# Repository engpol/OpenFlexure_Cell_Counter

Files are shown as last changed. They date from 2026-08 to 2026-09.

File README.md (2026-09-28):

# OpenFlexure Cell Counter

A simple automated cell counter built on the [OpenFlexure Microscope](https://openflexure.org/),
using either traditional contrast-based or deep-learning segmentation to count cells in suspension to assist in calculating
concentrations — all in under 60 seconds, without a haemocytometer!

### Cell Counter

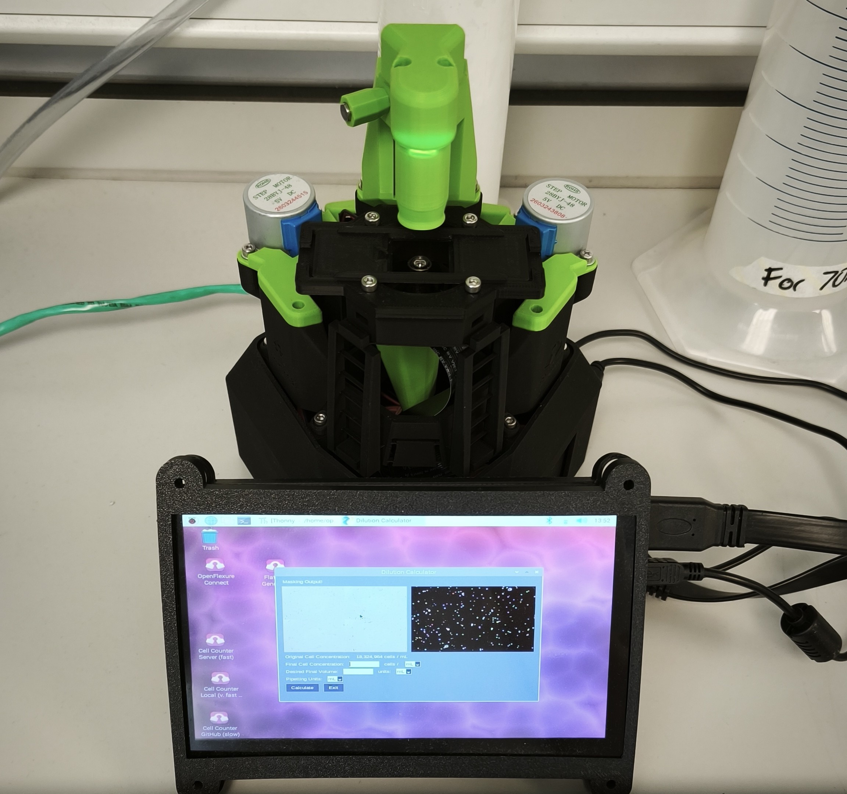
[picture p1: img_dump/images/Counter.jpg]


### GUI

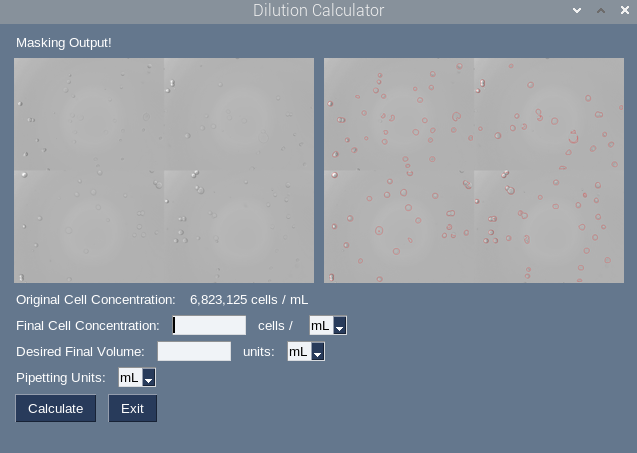
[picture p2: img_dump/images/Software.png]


---

## Contents

- [What this is](#what-this-is)
- [Who it's for](#who-its-for)
- [How it works](#how-it-works)
- [What you'll need](#what-youll-need)
- [Getting started](#getting-started)
- [Daily use](#daily-use)
- [Validating your instrument](#validating-your-instrument)
- [Limitations](#limitations)
- [Troubleshooting](#troubleshooting)
- [Contributing](#contributing)
- [Licence and citation](#licence-and-citation)

---

## What this is

Counting cells with a haemocytometer is slow, tedious, and notoriously variable
between operators. Automated cell counters solve this but cost several thousand
pounds, lock you into proprietary consumables, and are impossible to repair yourself.

This project turns an [OpenFlexure Microscope](https://www.youtube.com/watch?v=InmLDDsRmb4) — an open-source, 3D-printed,
motorised microscope — into an automated cell counter. You pipette your suspension onto a coverslip, press a button, and get a cell count and
concentration back in a few seconds. To see the cell counter in action [click here!](#daily-use)

>As a side-note, the microscope is a fully motorized and customisable brightfield microscope; the software provided here is simply a single use-case. If you ever invest in a professional cell counter, this can easily be re-purposed for another project!

There are 2 options for performing cell segmentation; either a traditional threshold-and-watershed approach or one that uses [Cellpose](https://www.cellpose.org/), a deep-learning model that handles
touching, overlapping, and irregularly shaped cells far better.

The Cellpose model included in this repo is **cyto2** fine tuned on images of HEK-293 cells taken on several different OpenFlexure microscopes. It is very easy to use it, or even one you have trained yourself, and it is covered in the server setup guide.

### Accuracy of Cell Counter

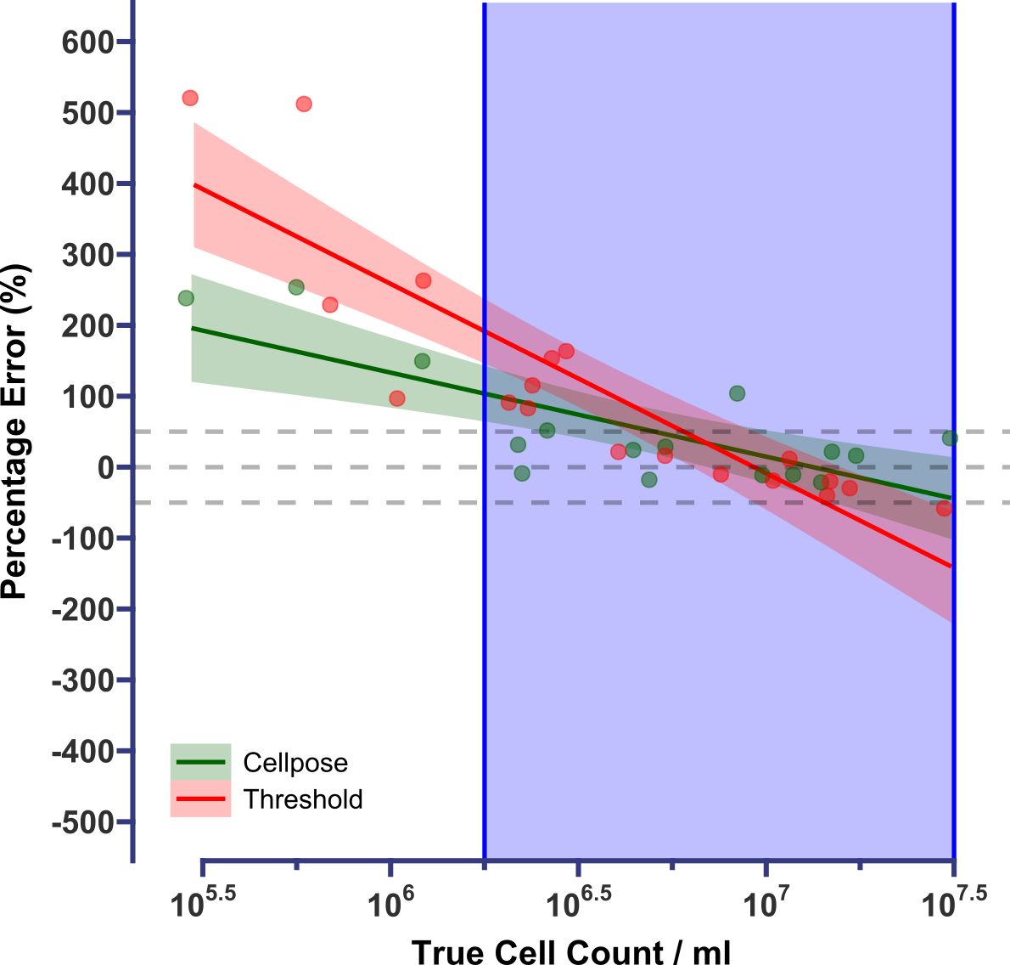
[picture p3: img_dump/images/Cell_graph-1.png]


**Shown above is a comparison of the cell counts given by my cell counter to those calculated by an Invitrogen Cell Countess to get an estimate of the expected error at different suspension concentrations.**

Across most of the range of initial concentrations of cell suspensions from semi-confluent to confluent T25-T175 flasks (*blue box*), both methods performed similarily and varied by less than 50% (*grey dotted line*) from the Cell Countess. 

### In this range, a **mean error** of **19.1%** (*Cellpose*) and **34.2%** (*Threshold*) were achieved. 
This is within the range of [expected error in manual cell counting](https://chemometec.com/how-to-count-cells-with-a-hemocytometer/) (20-30%) which makes both methods suitable substitutions to the use of a haemocytometer for a lot of cell culture experiments.

---

## Who it's for

>This Cell Counter is for people working in cell culture who routinely need to perform cell suspension dilution calculations, who may not need/want to spend thousands on more advanced systems. 

This counter, as the OpenFlexure Microscope itself, is designed to be assembled and be usable by someone with **no programming or engineering experience**. The setup involves a few one-time steps for which detailed click-by-click guides have been written out; after that, daily use is a graphical interface with a few buttons.

You will need to be comfortable with:

- Pipetting onto a coverslip
- Following a step-by-step setup guide once

You will **not** need to write your own code, use a command line day-to-day, or
understand how the machine learning works. However, information on all of the code is provided if you would wish to adapt/improve on what I have made here. 

---

## How it works

The process of counting cells is functionally identical to what can be done manually in a haemocytometer. However we can use the fact that the exact effective field of view of the camera is known, to forgo the need for a machined chamber.  

The microscope photographs **four fields of view**, which together cover a small
fraction of the coverslip:

| Quantity | Value |
|---|---|
| Area of one field of view | 0.0584 mm² |
| Four fields combined | 0.2336 mm² |
| Area of a 22 × 22 mm coverslip | 484 mm² |
| **Fraction of the sample you actually see** | **1 / 2072** |

Then the microscope will use one of either methods to calculate the number of cells across all 4 images.

So if the microscope counts 150 cells:

```
Total cells on coverslip  = 150 × 2072  = 310,800 cells
Volume pipetted           = 50 µL       = 0.05 mL
Concentration             = 310,800 / 0.05 = 6.2 × 10⁶ cells/mL
```

This calculation only works on assumption the cells are **evenly distributed** across the coverslip. Thus it is important to let the
sample settle, mix it thoroughly before pipetting, and take a second reading if a
number looks surprising.

---

## What you'll need

### Hardware

| Item | Notes | Approx. cost |
|---|---|---|
| [OpenFlexure Microscope](https://openflexure.org/) | Simple optics are sufficient and use most up-to-date hardware version | ~100£ or ~160£ from a vendor (Exluding RPi) |
| Raspberry Pi 4B | I used 4GB model, but 2 GB should be sufficient | These have recently got more expensive, so including separate to microscope. Expect 50-90£ |
| Microscope Peripherals | You'll need a seperate screen/mouse + keyboard to control the microscope. The cost will depend on how compact you want it to be. I used a [very small screen](https://www.amazon.co.uk/ELECROW-Touchscreen-1024x600-Compatible-Raspberry/dp/B0G5YL9Z66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) I found on amazon and an old bluetooth mouse/keyboard I found in the office. | Existing hardware or ~50£ |
| Analysis computer (Optional) | Any old PC that can be connected to the scope via an ethernet cable. Helps tremendously if it has any NVIDIA Graphics card supporting CUDA, but is not an absolute requirement. | Existing hardware |
| Ethernet cable (Optional) | Ordinary cable | ~£5 |
| 22 × 22 mm glass coverslips | Whatever's cheapest, I just wash and re-use mine until they crack | £5 |
| Additional 3D-printed parts | The 2 STLs in [`STLs/Custom_Holder`](STLs/Custom_Holder/) | Filament cost or ~10£ if using external service |

### Total Cost:

**~ 200£** (Excluding optional Analysis PC/peripherals - the cost of this will vary depending on what you have lying around) 

### Software

Everything needed is free and open-source. The easiest way to get the cell counter running is by using the pre-configured image which can be downloaded using the button below (~9.1 GB). In time, I may try to get this working as a PyPi package.



---

## Getting started

Budget about **two hours** for first-time setup, excluding building the microscope.

### 1. Build the microscope

Acquire all parts required for the "Basic Optics" variant of the Open Flexure Microscope, and follow the [OpenFlexure assembly instructions](https://build.openflexure.org/) to build the microscope. Please check out the list of [associated vendors](https://openflexure.org/about/vendors) if you would prefer to simply buy a complete assembly kit for the microscope. I have included all STL files needed for the [OpenFlexure v7](STLs/OpenFlexure_v7_Beta) in this repo for your benefit. 

Then, once you have finished the build, just screw on the [`counting chamber`](STLs/Custom_Holder/counting_chamber.stl) from [`STLs`](STLs/Custom_Holder) onto the sample stage using 4 M3 bolts (the same type that you used to hold the sample clips in place). 

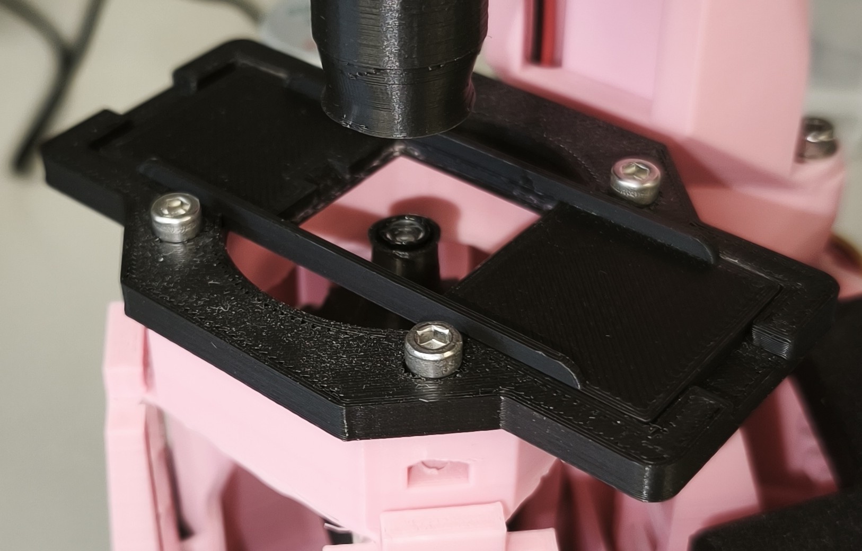
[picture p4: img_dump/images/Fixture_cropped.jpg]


### 2. Flash the Raspberry Pi

Download the pre-configured image (link above) and write it to an SD card with
[Raspberry Pi Imager](https://www.raspberrypi.com/software/). Put the SD card into your OF microscope, and boot it up. Everything —
base OpenFlexure microscope software, network settings, Cell Counter software — is already installed. 

I recommend a 32 GB SSD, but anything above 10 GB should be fine.
The thresholding-watershed method for Cell Segmentation can run directly from the RPi so, if you do not wish to run Cellpose, this is all you would need to have a functional Cell Counter!

### 3. OPTIONAL - IF USING CELLPOSE - Set up Server

If wanting to use Cellpose for segmentation, you will need a second computer to run the Cellpose segmentation. 

Sadly, some of the Cellpose dependencies (Torch) are very hard to setup and run dreadfully slow on the 32-bit ARM OS that is required by the OFM. Even after getting it working in my trials, running CellPose on even a couple images on the OFM itself took ~ 15 mins, making it non-viable for daily use.

If you have any old PC lying around, this can be turned into a "server" which can process images taken on the OFM Cell Counter. The process outlining how to do this can be found in [docs/SERVER_SETUP](docs/server_setup/SERVER_SETUP.md).

The server setup assumes that you may not have full admin rights/control over your WiFI network (As is the case for me, using institutional WiFi). This is why, at least in my guide, the server will have to be directly connected to the Cell Counter via an ethernet cable. Keep this in mind if you are short on space/were hoping to have the server placed in a different room to the cell counter.

### 4. Initial Setup and taking Flatfield Image

#### Whichever method you use for segmentation, please follow the proceeding steps before beginning to use the cell counter for the first time.

**Don't skip this.** 

Connect to your microscope using [**OpenFlexure Connect**](https://openflexure-microscope-software.readthedocs.io/en/latest/webapp/pane_navigate.html) tool which gives you full control of your microscope. 

TLDR: you can use the mouse scroll wheel to focus, and keyboard arrows to move the stage in all 4 directions. You can change the sensitivity of the movement in the **Navigate** tab.

You may notice the screen looks entirely white. To correct this, from within **OpenFlexure Connect** click **Settings** -> **Camera** and Click **Full Auto-Calibrate**.

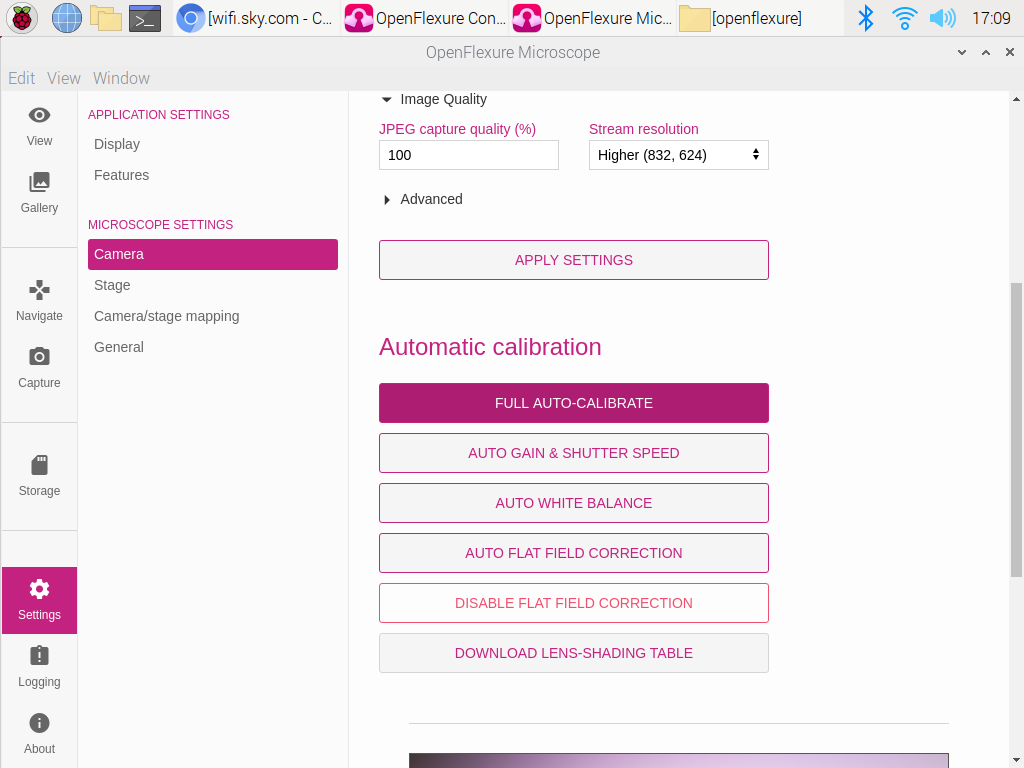
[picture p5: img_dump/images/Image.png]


This should correct the camera parameters and give you a more reliable image in the **View** tab.

Also, before you can use the cell counter you will need to provide it with a Flat-field image to correct for unevern illumination. 

To do this, mount **50 µL** of whichever medium you usually dilute your cells in (DMEM etc.). 

Then, using **OF Connect**, make sure you are completely centered on your sample holder and fully **out of focus**

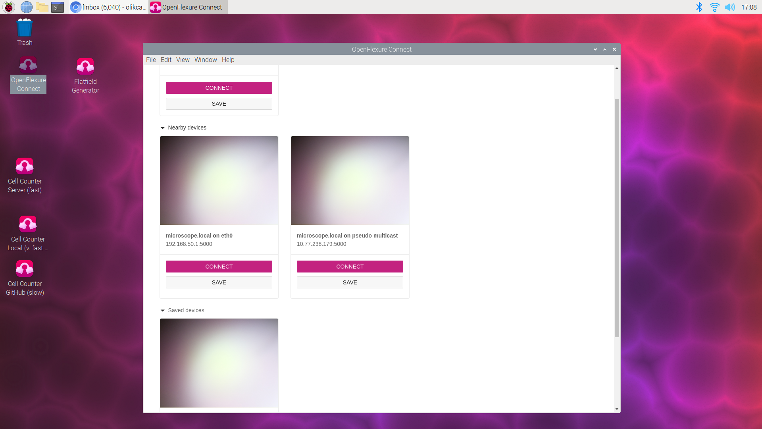
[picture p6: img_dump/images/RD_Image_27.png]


Then, boot up the Flatfield generator - short cut can be found on desktop - and press **'Ok'**

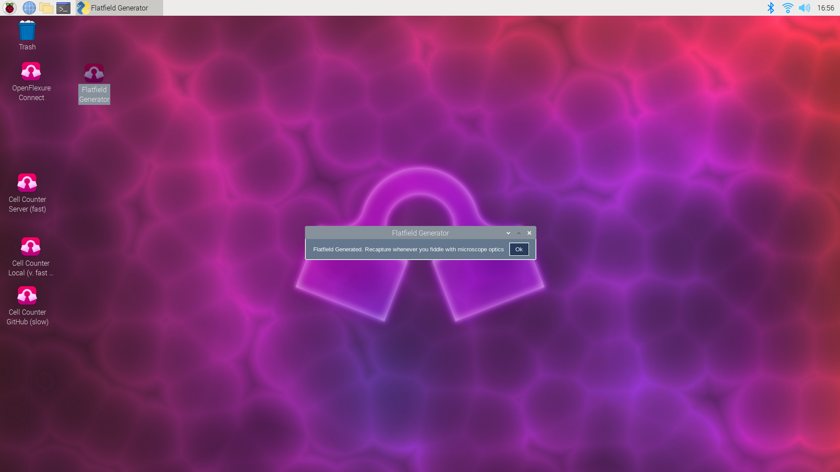
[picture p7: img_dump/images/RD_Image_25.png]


After a short amount of time, the microscope will take a sufficient number of images to generate that flatfield that will be used to correct your images! 



Optionally, run the calibration described in
[Validating your instrument](#validating-your-instrument) before using the
counter for real experiments.

### 5. Use for Cell Counting

The Cell Counter should now be fully setup. Use to your hearts content!

---

## Daily use 

A video showing the entire process can be found below:

https://github.com/user-attachments/assets/5db055de-96ec-4996-82e9-81a2b3afec3e

1. Turn on the microscope (and optionally the analysis computer - the analysis service starts
   by itself.)

2. Pipette **50 µL** of cell suspension onto a 22 × 22 mm coverslip and mount it using a second coverslip.

3. If this is the first time you have used the microscope/haven't used it in a while, focus on your cells using **OpenFlexure Connect**

4. Launch the appropriate Cell Counter using the Desktop Shortcut:
    - **Cell Counter Server (fast)** = Use Cellpose (requires ethernet connection to a configured analysis computer/server)
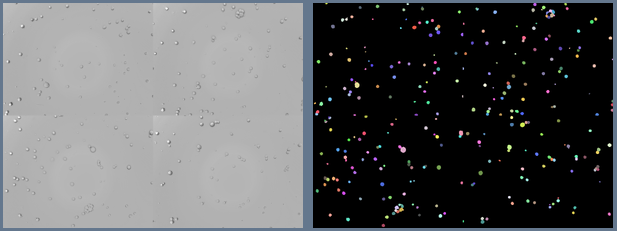
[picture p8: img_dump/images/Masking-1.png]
    
    - **Cell Counter Local (very fast)** = Use Contrast-based Thresholding (runs on the OFM itself) 
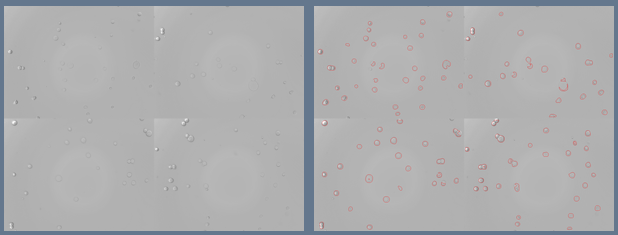
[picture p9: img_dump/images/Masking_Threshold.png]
    

5. Press **Ok**. The microscope performs an autofocus and takes four images across the 
coverslip.

6. Results appear in a few seconds:
   - Total cells counted
   - Concentration in cells/mL
   - An image showing exactly which cells were counted
   - **Use the on-screen calculator to perform desired dilution calculations**

**Always look at the outline image.** It's the quickest way to spot a bad count —
debris counted as cells, clumps counted as one, or cells missed because the
focus drifted. If there are any problems, try to ammend them, and count again. 

If the focus has drifted far too much, you may need to re-focus using the **OpenFlexure Connect** tool, which gives you full control over the microscope.

---

## Validating your instrument

Every build is slightly different. Two checks before you trust the numbers.

### 1. CELLPOSE 

Cellpose needs to know roughly how large your cells are, in pixels. Getting this wrong affects both accuracy and speed. If you are finding that you are getting poor segmentation on your cells, before deciding to train your own model, it is worth checking that changing the diameter parameter won't fix your issues. 

As outlined above, this Cell Counter was validated and setup for HEK-293 cells (where I found a diam value of 15.328 worked best). However, if your cells are significantly smaller/larger, you may need to adjust this parameter.

To find a good value for this, take a couple images of your cells on your OFM and send it to a PC capable of running cellpose. You will essentially be wanting to open the [Cellpose GUI](https://cellpose.readthedocs.io/en/latest/gui.html), import this image, and press the 'Calibrate' button to find a recommended diameter value. 

You can also follow this [YouTube guide](https://www.youtube.com/watch?v=5qANHWoubZU) to see how to do this in more detail (From start until ~7 mins in). If you watch the rest of the tutorial, you could also at this point train a custom model for your microscope to use instead, which may work much better. The final step in [docs/SERVER_SETUP](docs/server_setup/SERVER_SETUP.md) goes over how to get the server to use your custom model instead. 

Once you have the recommended diameter value, change it in the worker file on the server using `sudo systemctl edit --full cellcounter-worker`, and changing the "CELLCOUNT_DIAMETER" parameter. 

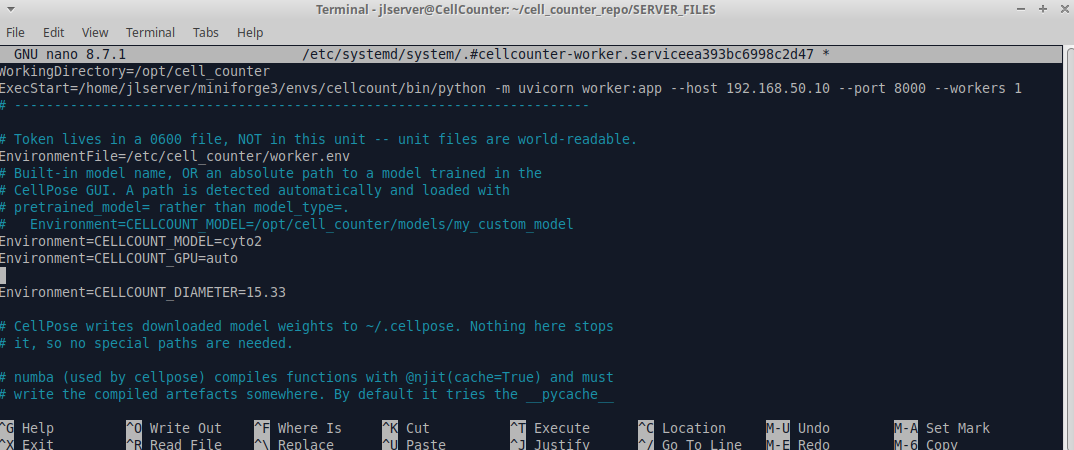
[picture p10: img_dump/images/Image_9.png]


### 2. Compare against a haemocytometer

Run the same suspension both ways, across at least three different
concentrations spanning your working range. They should agree within the
haemocytometer's own variability.

If they disagree systematically:

| Pattern | Likely cause |
|---|---|
| Counter always reads **high** | Debris counted as cells (more of an issue when testing suspension concentration is low), the four fields overlap so some cells are counted twice |
| Counter always reads **low** | Cells out of focus, diameter set too small, or cells too sparse |
| Disagreement grows with concentration | Cells clumping, or overlapping cells merged into one object |

---

## Limitations

Being upfront about these:

- **Not a validated clinical or diagnostic device.** This is a research tool.
- **Cells must be reasonably well separated.** Dense or heavily clumped
  suspensions could undercount, as clumps get merged.
- **Poor performance at very low concentrations.** As the stage movement is relatively slow and speed is paramount, at low suspension concentrations, only using 4 FOV means the camera will capture very few cells. This means the error can become quite large. Only use this cell counter for splitting/diluting down cell suspensions from relatively confluent flasks 

- **No viability staining.** This counts cells, it does not distinguish live from
  dead. Trypan blue exclusion is not currently supported.
- **Assumes even settling.** Uneven distribution across the coverslip is the
  largest single source of error.
- **Field-of-view geometry is build-specific.** The area constants assume the a specific optics module and camera used in the 'Basic Optics' configuration of the OFM; if you change either, you would have to re-calibrate and modify some of the code.
- **The four fields may overlap slightly.** Stage movement is calibrated in
  motor steps rather than measured distance, so a small overlap can cause modest
  double-counting. Double check in the output no overlap is present. Changing motor steps to correct for overlap is covered [here](docs/Cell_Counter_Docs.md).

---

## Troubleshooting

| Problem | What to check |
|---|---|
| Count is obviously wrong | Look at the outline image. Usually focus, or the diameter setting |
| Everything counted as one big blob | Diameter set far too large |
| Nothing detected at all | Diameter set far too small, or the image is out of focus |
| Analysis takes minutes, not seconds | The service restarted and is reloading the model — the first run after startup is always slower |

More detail in [docs/Cell_Counter_Docs](docs/Cell_Counter_Docs.md) and [docs/Server_Setup](docs/Server_Setup.md).

Still stuck? [Open an issue](../../issues) with the error message, what you were
doing, and a photo of the result image if relevant.

---

## Contributing

Contributions are very welcome, especially:

- Validation data from other cell types or labs
- Improvements to the 3D-printed parts
- Support for viability staining
- Testing on Linux or macOS analysis computers

Please open an issue before starting substantial work, so we can avoid
duplication.

---

## Licence and citation

If you use this in published work, please cite the underlying tools:

**OpenFlexure Microscope**
Collins, J.T. et al. Robotic microscopy for everyone: the OpenFlexure
microscope. *Biomedical Optics Express* **11**, 2447–2460 (2020).

**Cellpose**
Stringer, C., Wang, T., Michaelos, M. & Pachitariu, M. Cellpose: a generalist
algorithm for cellular segmentation. *Nature Methods* **18**, 100–106 (2021).

Pachitariu, M. & Stringer, C. Cellpose 2.0: how to train your own model.
*Nature Methods* **19**, 1634–1641 (2022).

---

## Acknowledgements

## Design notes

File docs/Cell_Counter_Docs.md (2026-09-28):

# OFM Cell Counter Server Setup
## Contents

## Introduction

This will be a place I will attempt to provide documentation on the Cell Counter software. A lot can be found in the README, but I will try to add more in-depth info here with time. 

## Cell Counter Application

All of the cell counter analysis scripts live in the `/home/openflexure/Applications/Cell_Counter` directory. If you want to modify most of the parameters of analysis, it will be in scripts found here. 

The desktop shortcuts link to one of 2 scripts found here:

1. The **Cell Counter Server** shortcut runs: `Cell_Counter_Main.py `

2. The **Cell Counter Local** shortcut runs `Cell_Counter_Main_Local.py`

Depending on which method you use for segmentation, you will want to make edits to the appropriate file. Some files are shared between the 2 approaches, so edits here will affect both scripts. 

## Changing Amount of Cell Suspension Used

If you find yourself wanting to use a different mounting volume of cell suspension (perhaps you may want to use a hemocytometer instead of the 22mm coverslips I suggest) then you will want to make an edit to line 168 in the above scripts

```python
cell_concentration = (cell_number_FOV * 3249.10716683)/0.05
```

0.05 denotes the volume  of the cell suspension in litres, so just change accordingly (e.g. 0.01 for 10 microliters).

## Modifying Motor Steps

If you find you have significant overlap between your FOV captured, you may need to change the amount of steps the stage moves before taking an image. 

To find out which step size would be best, run the **OFM Connect** tool, and use the **Navigate** tab to move the stage left/right and up/down, and see the minimum number of steps required to cover the size of the eFOV of the camera (i.e. move to an entirely new region of the coverslip). 

Then in `Microscope_Control_Functions.py`, change all of the `pos['x']` integers to the steps required to move the stage in the x plane (i.e. 'left-right'), and change all of the `pos['y']` integers to the steps required to move the stage in the y plane (i.e. 'up-down'). 

For example, if I required 12000 steps to move to a new FOV in the X, I would change `pos['x'] += 8400` to `pos['x'] += 12000`

```python
def Image_Acquisition(progress_callback):
    microscope = ofm_client.find_first_microscope()
    ret = microscope.autofocus() ## autofocus micro
    img_1 = microscope.capture_image()
    img_1.save("/home/openflexure/Applications/Cell_Counter/captured_images/image_1.tiff", format="tiff")
    progress_callback(1)
    pos = microscope.position
    starting_pos = pos.copy() ## for checking if final position is same as starting one, if not something has gone wrong
    pos['x'] += 8400
    microscope.move(pos)
    assert microscope.position == pos
    img_2 = microscope.capture_image()
    img_2.save("/home/openflexure/Applications/Cell_Counter/captured_images/image_2.tiff", format="tiff")
    progress_callback(2)
    pos['y'] += 6400
    microscope.move(pos)
    assert microscope.position == pos
    img_3 = microscope.capture_image()
    img_3.save("/home/openflexure/Applications/Cell_Counter/captured_images/image_3.tiff", format="tiff")
    progress_callback(3)
    pos['x'] -= 8400
    microscope.move(pos)
    assert microscope.position == pos
    img_4 = microscope.capture_image()
    img_4.save("/home/openflexure/Applications/Cell_Counter/captured_images/image_4.tiff", format="tiff")
    progress_callback(4)
    pos['y'] -= 6400
    microscope.move(pos)
    assert microscope.position == starting_pos
    #img_5 = microscope.capture_image()
    #img_5.save("/home/openflexure/Applications/Cell_Counter/captured_images/image_5.tiff", format="tiff")
    progress_callback(5)
```

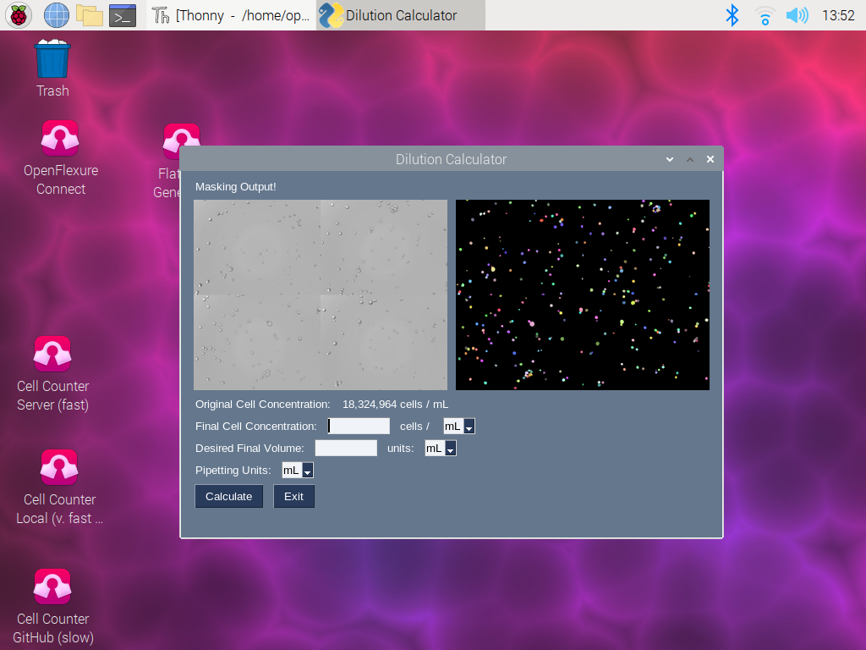
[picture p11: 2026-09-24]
img_dump/images/RD_Image_30.png

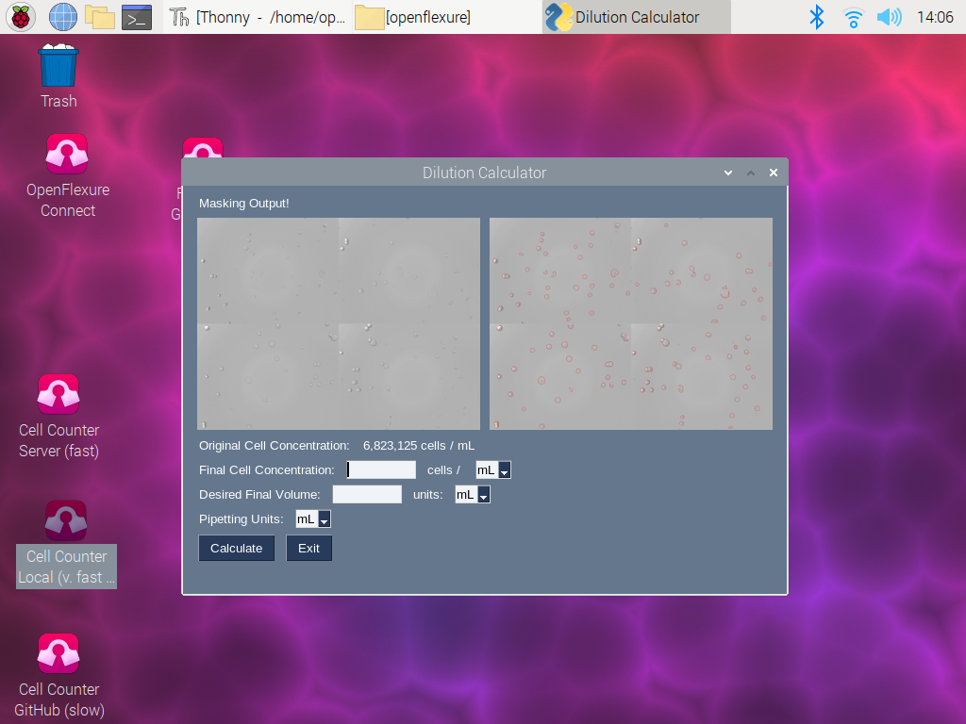
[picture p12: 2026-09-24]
img_dump/images/RD_Image_32.png

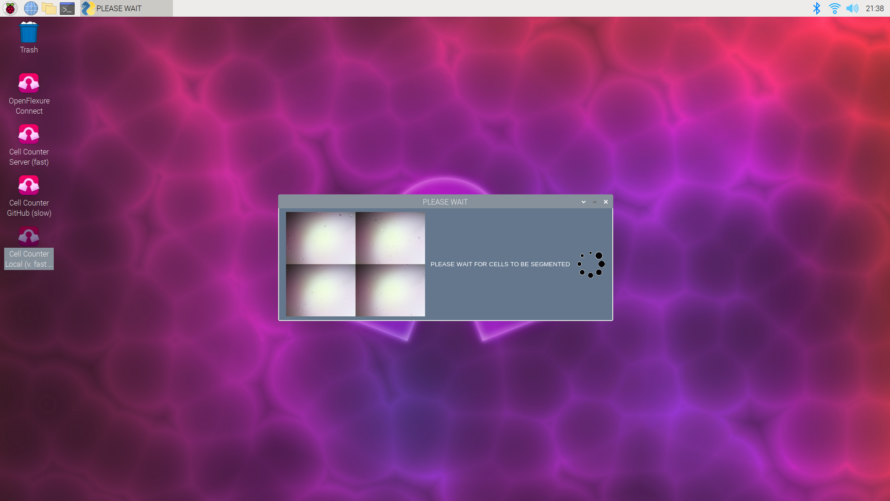
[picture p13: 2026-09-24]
img_dump/images/RD_Image_3.png

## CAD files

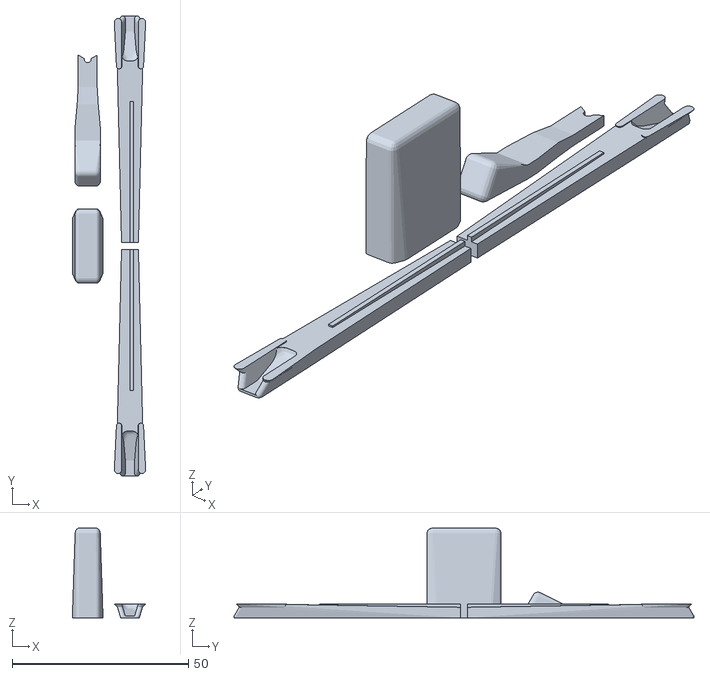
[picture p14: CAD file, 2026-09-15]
STLs/OpenFlexure_v7_Beta/actuator_assembly_tools.stl
20.8 x 130.5 x 25.5

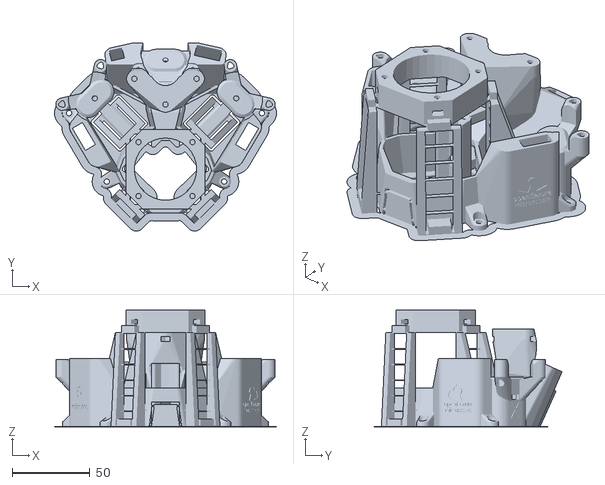
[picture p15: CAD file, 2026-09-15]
STLs/OpenFlexure_v7_Beta/Colour_1_PLA/main_body.stl
142.6 x 120.9 x 75.0

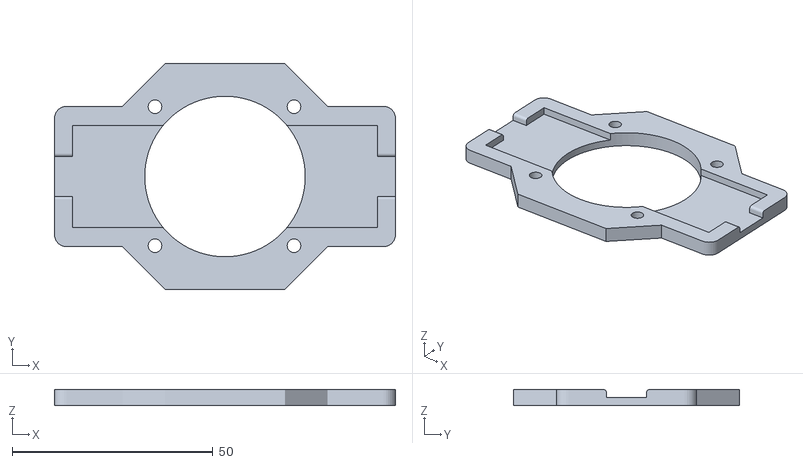
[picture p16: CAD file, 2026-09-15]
STLs/Custom_Holder/Custom_Slide_Holder.stl
85.0 x 56.2 x 4.00

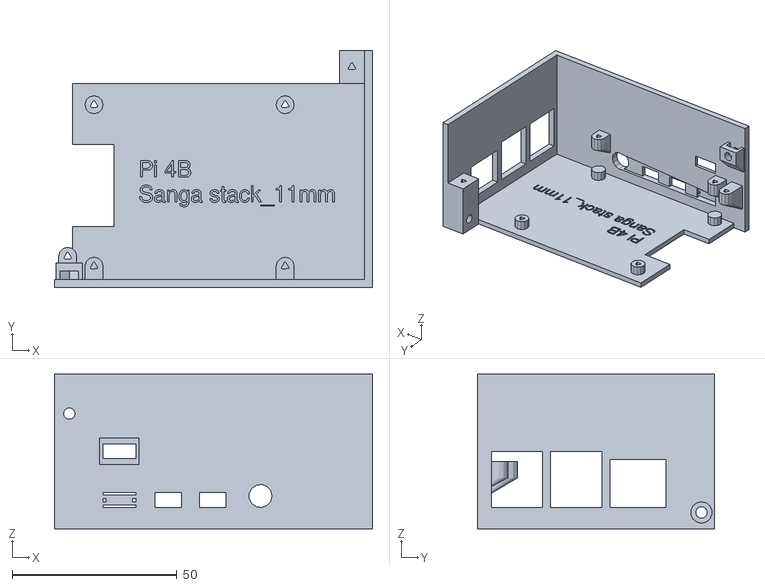
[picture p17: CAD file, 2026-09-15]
STLs/OpenFlexure_v7_Beta/Black_PLA/electronics_drawer-pi4_sanga_stack_11mm.stl
96.5 x 72.0 x 47.0

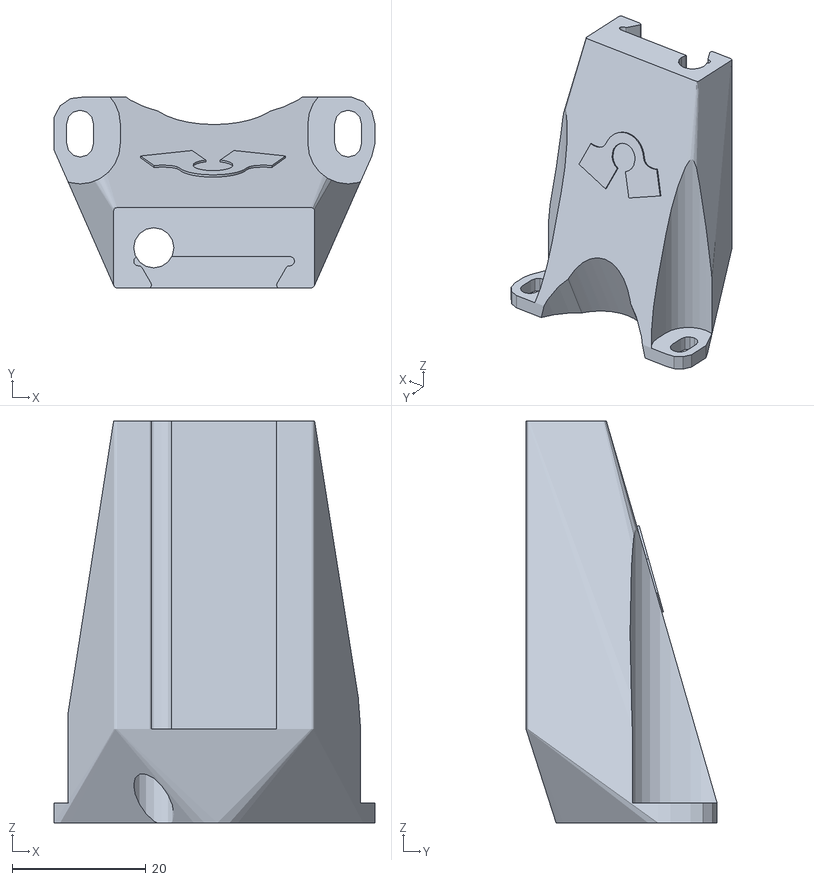
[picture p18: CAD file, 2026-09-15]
STLs/OpenFlexure_v7_Beta/Colour_1_PLA/illumination_dovetail.stl
47.9 x 28.5 x 60.0

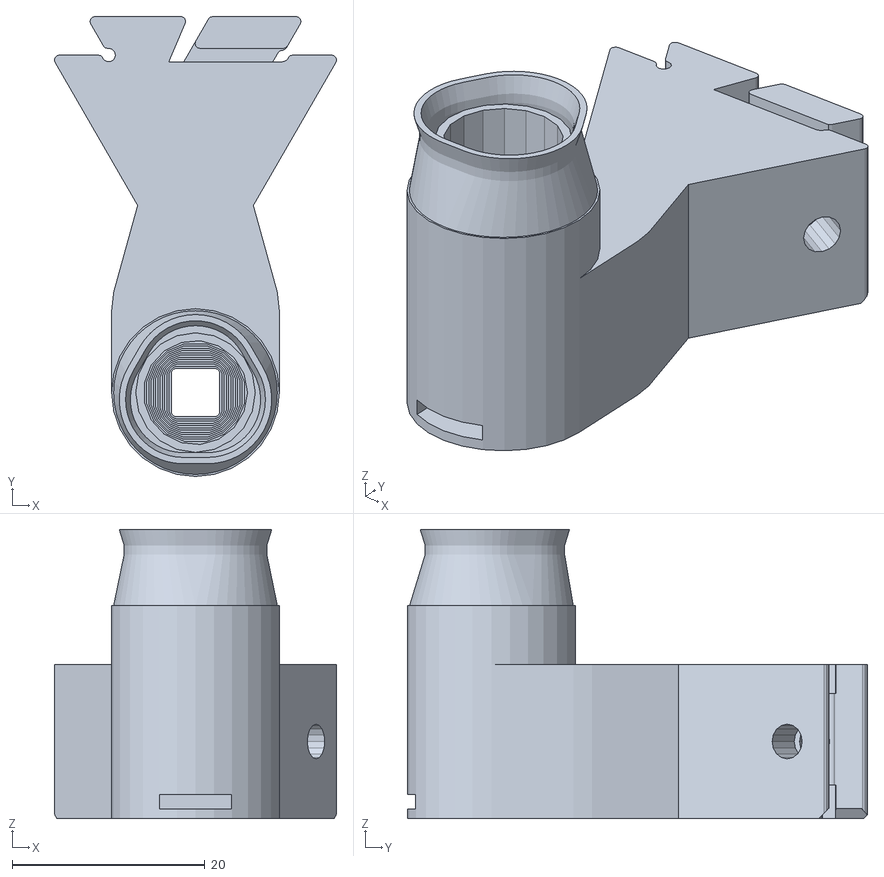
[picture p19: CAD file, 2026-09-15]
STLs/OpenFlexure_v7_Beta/Colour_2_PLA/condenser.stl
29.3 x 47.7 x 30.0

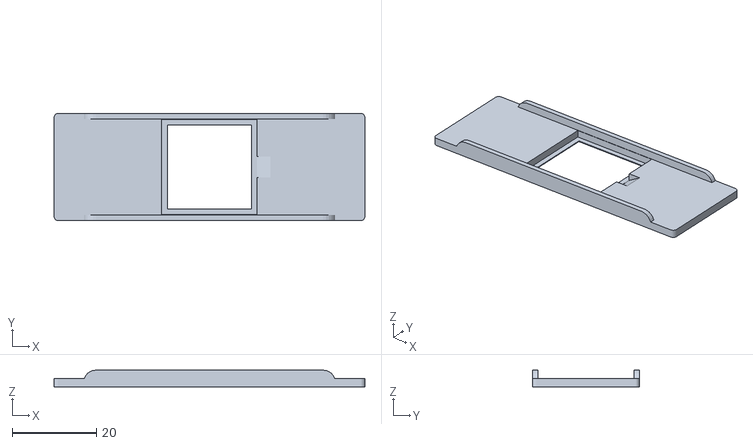
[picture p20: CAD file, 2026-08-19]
STLs/Custom_Holder/counting_chamber.stl
74.0 x 25.5 x 4.00

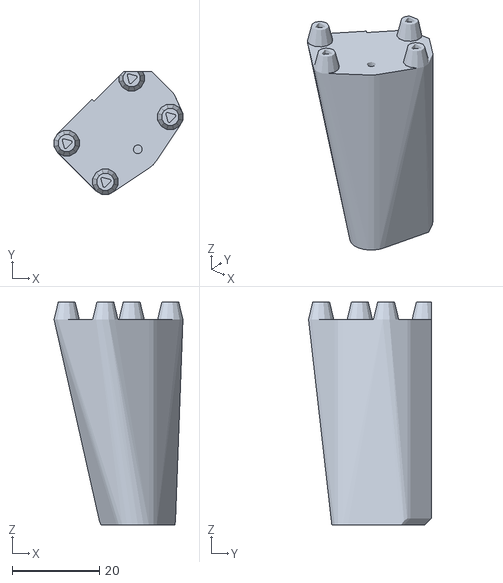
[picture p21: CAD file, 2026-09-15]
STLs/OpenFlexure_v7_Beta/Black_PLA/camera_platform_picamera_2_pilens.stl
29.5 x 28.1 x 51.0

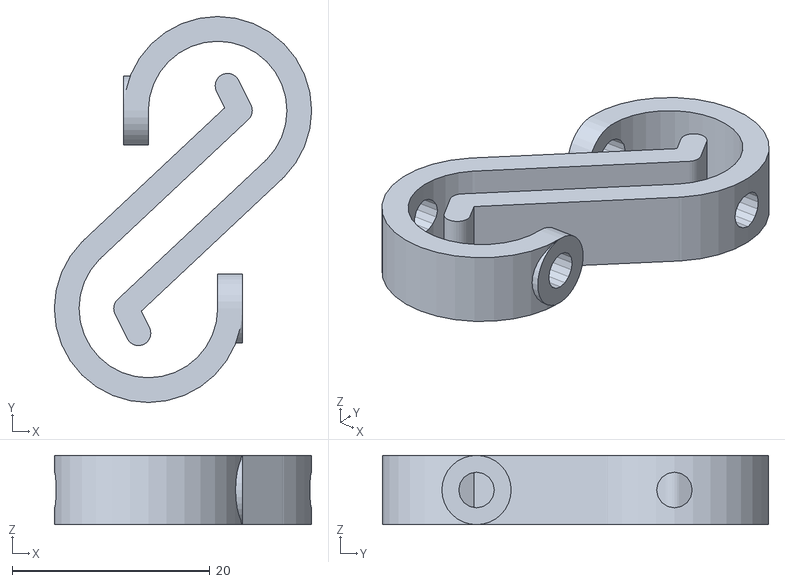
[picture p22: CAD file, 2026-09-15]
STLs/OpenFlexure_v7_Beta/Colour_2_PLA/sample_clips.stl
26.0 x 39.0 x 7.00

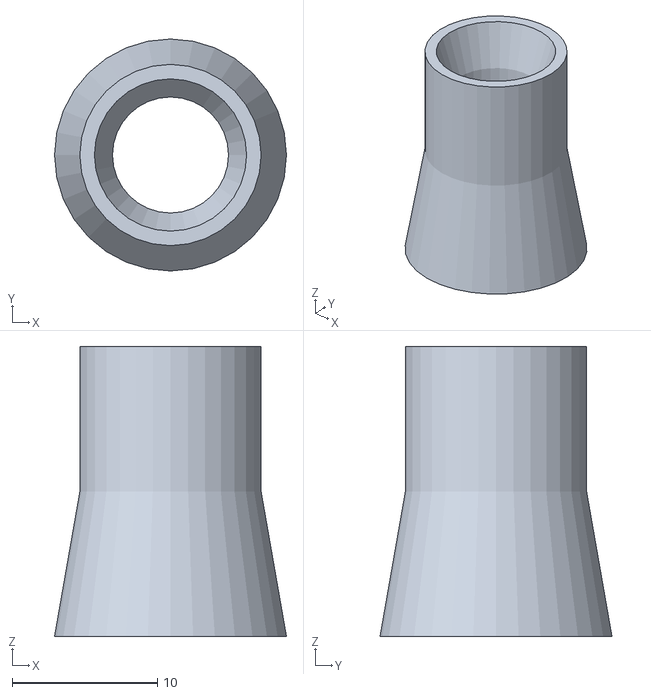
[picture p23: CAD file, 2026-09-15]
STLs/OpenFlexure_v7_Beta/lens_tool.stl
16.0 x 16.0 x 20.0

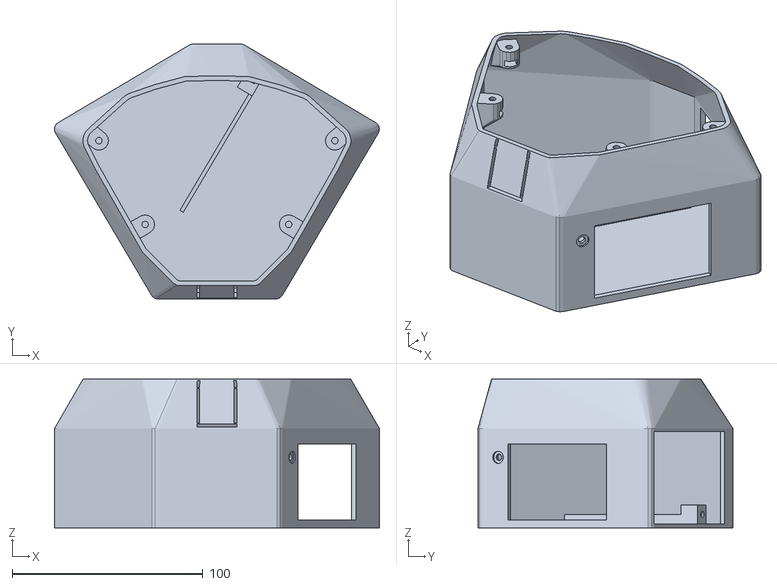
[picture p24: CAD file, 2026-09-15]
STLs/OpenFlexure_v7_Beta/Black_PLA/microscope_stand.stl
170.6 x 133.9 x 78.0

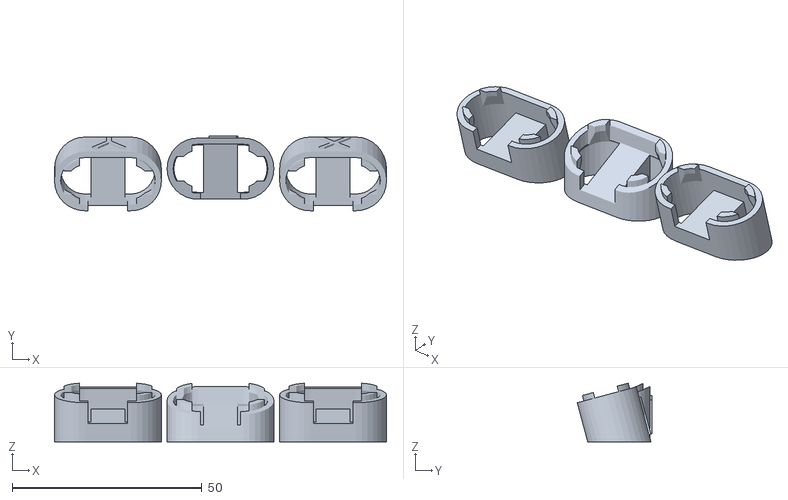
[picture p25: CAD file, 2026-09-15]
STLs/OpenFlexure_v7_Beta/Colour_1_PLA/feet.stl
87.6 x 19.7 x 15.5

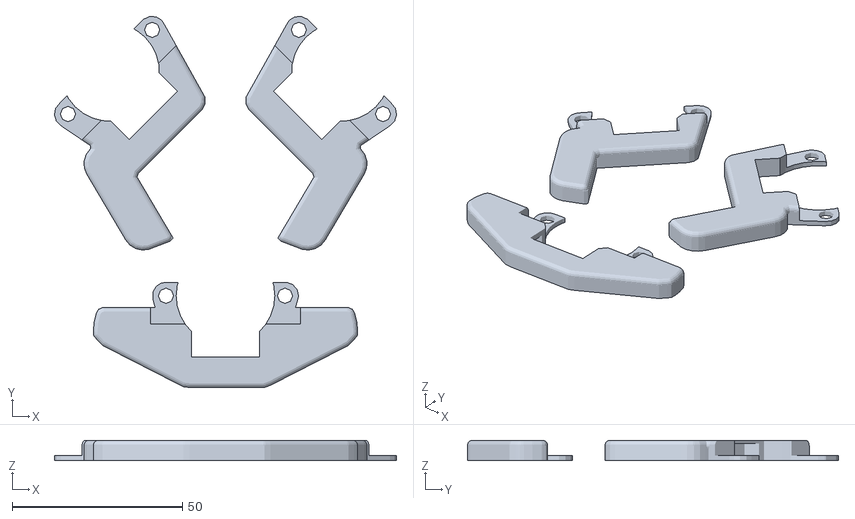
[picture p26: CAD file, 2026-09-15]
STLs/OpenFlexure_v7_Beta/Colour_2_PLA/cable_tidies.stl
100.6 x 109.1 x 6.03

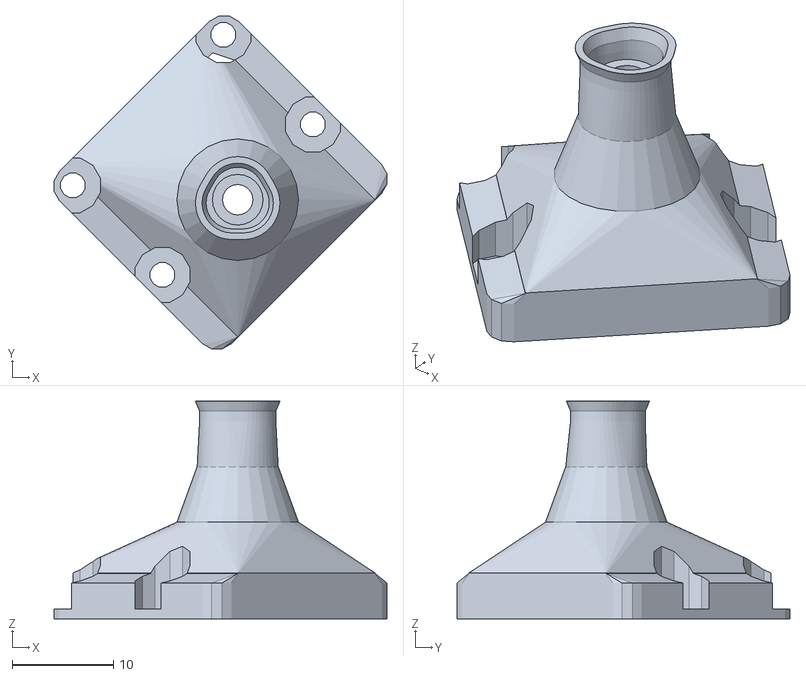
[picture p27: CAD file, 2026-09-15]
STLs/OpenFlexure_v7_Beta/Black_PLA/lens_spacer_picamera_2_pilens.stl
32.9 x 32.9 x 21.5

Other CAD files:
STLs/OpenFlexure_v7_Beta/Colour_2_PLA/large_gears.stl
STLs/OpenFlexure_v7_Beta/Colour_2_PLA/condenser_board_spacer.stl
STLs/OpenFlexure_v7_Beta/Colour_2_PLA/small_gears.stl
STLs/OpenFlexure_v7_Beta/Colour_2_PLA/condenser_lid.stl
STLs/OpenFlexure_v7_Beta/Colour_2_PLA/illumination_thumbscrew.stl

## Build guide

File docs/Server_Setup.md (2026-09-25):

# OFM Cell Counter Server Setup

## Introduction

This guide will cover how to setup a server to run CellPose models for improved cell segmentation on the OFM Cell Counter. Screenshots will be provided for most steps, but unless otherwise stated, **all** of the commands presented here will have to be ran in terminal on the server. 

Time: about 2-3 hours

---

## 0: Before you start…

What you will require:

### Hardware

- Any PC (from roughly the last 10 years), 8 GB RAM, ~20 GB free disk.
- A spare Ethernet port. A USB-Ethernet adapter works.
- An ordinary Ethernet cable.
- An NVIDIA GPU in the PC. This is **optional,** but speeds up model run-time. See step 3.
- USB Stick - at least 8 GB - for installing Linux on the server

### OS Setup

This guide assumes the server is running **Xubuntu 24.04 LTS** (or Lubuntu / Linux Mint XFCE — any works). Download: [https://xubuntu.org/download/](https://xubuntu.org/download/). It is recommended to do a fresh install of this on the PC. Please see the [following guide](https://docs.xubuntu.org/user/pt/installation.html) on how to install XUbuntu onto any PC (You will need an empty USB stick with at least 8 GB of storage space).

During installation, note the username you create. This guide uses `jlserver`; I recommend sticking with this during installation, if you change it, you may have to substitute it in any commands that are run.

**Temporary internet access is required** for steps 2–4 (package downloads and the CellPose model weights). After setup the server needs no internet.

Once you have installed Xubuntu on your server and have internet access, continue

---

## **1. Get the files onto the server**

Open up terminal on your server:

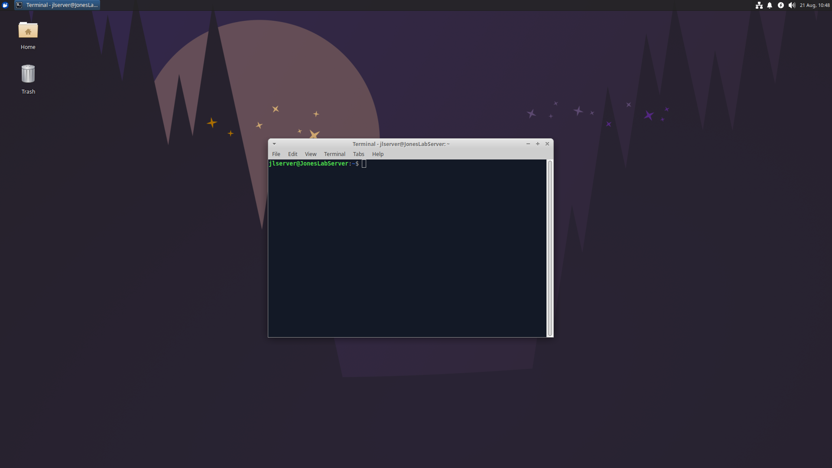
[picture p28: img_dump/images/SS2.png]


In the terminal, run the following code. You can copy it from this block, paste it in the terminal and press Enter.  This will copy all required files from the repo onto the server.

```python
sudo apt update
sudo apt install -yimg_dump
git clone https:/img_dump.com/engpol/OpenFlexure_Cell_Counterimg_dump ~/cell_counter_repo
cd ~/cell_counter_repo/SERVER_FILES
```

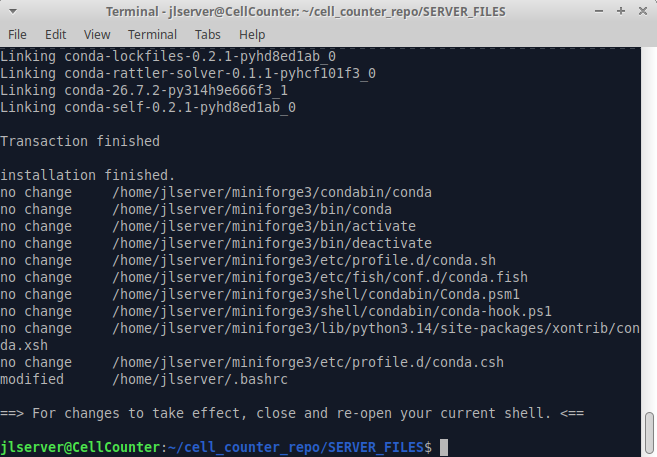
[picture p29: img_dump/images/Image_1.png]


---

## 2: Install Python via Miniforge

Now run the following command block inside the terminal to install Python onto the server. 

```python
wget https:/img_dump.com/conda-forge/miniforge/releases/latest/download/Miniforge3-Linux-x86_64.sh
bash Miniforge3-Linux-x86_64.sh -b -p "$HOME/miniforge3"
source "$HOME/miniforge3/etc/profile.d/conda.sh"
conda init bash
```

(Some SS of what this should look like)

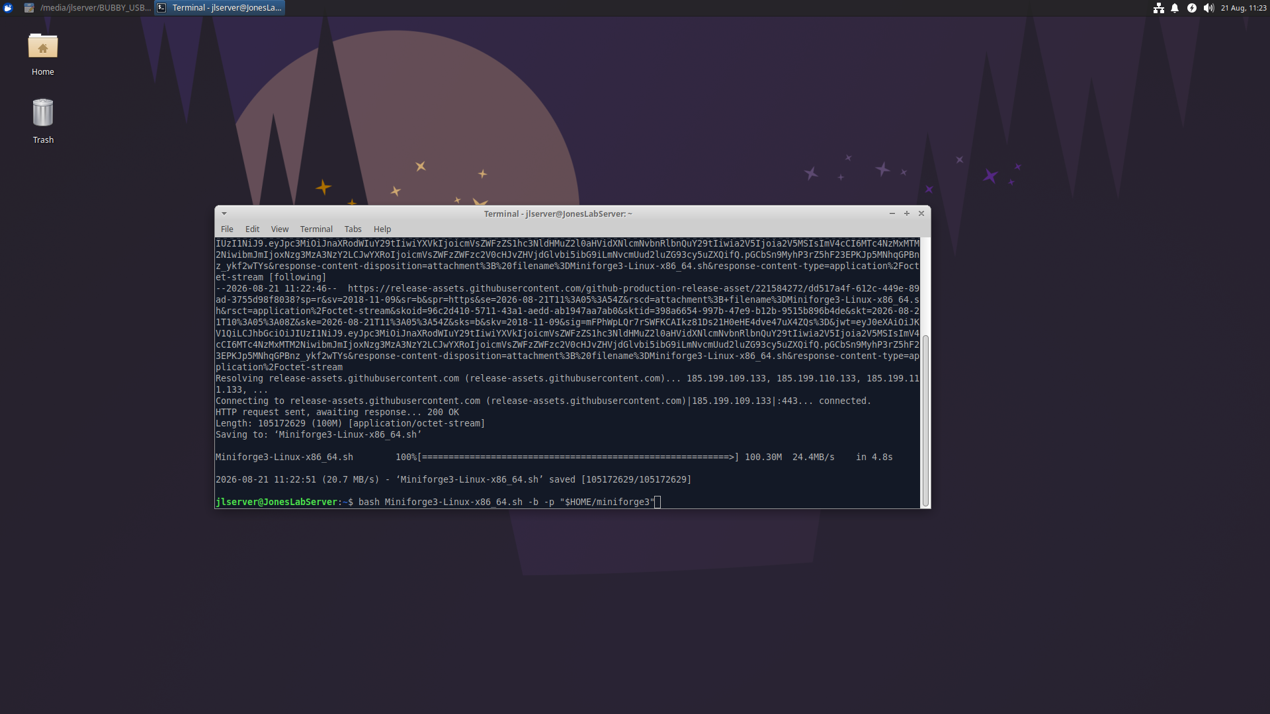
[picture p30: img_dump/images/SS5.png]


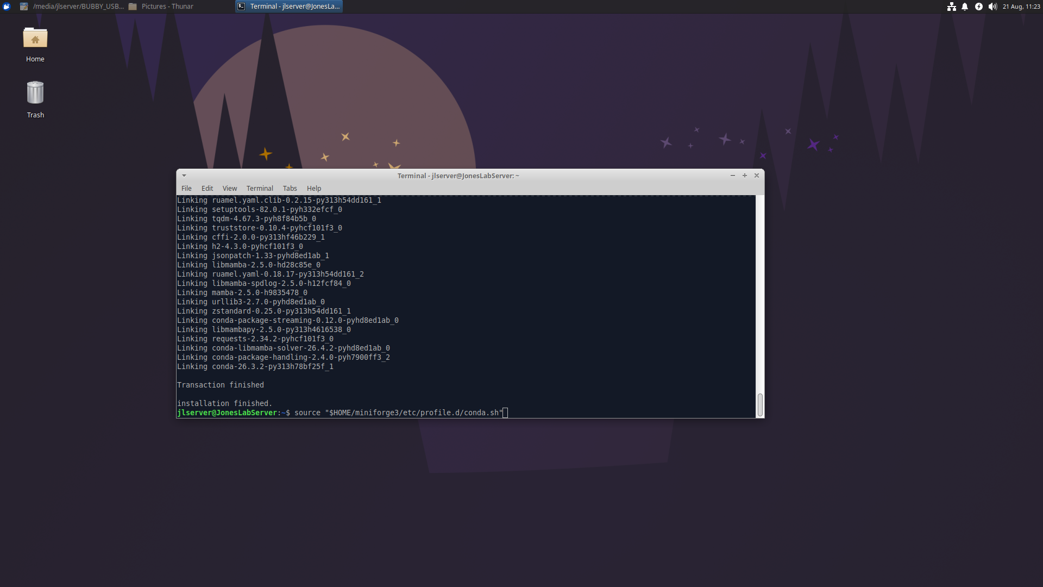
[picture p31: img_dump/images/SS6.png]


Now Close and reopen the terminal, then run the following code block to create the virtual environment which will run the python code. 

```python
cd ~/cell_counter_repo/SERVER_FILES
conda create -n cellcount python=3.10 -y
conda activate cellcount
```

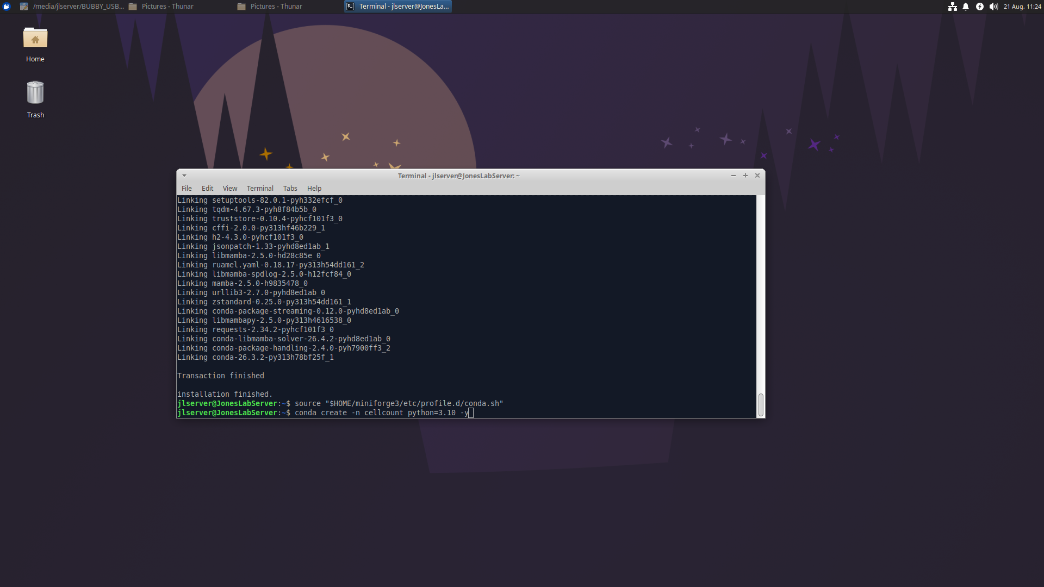
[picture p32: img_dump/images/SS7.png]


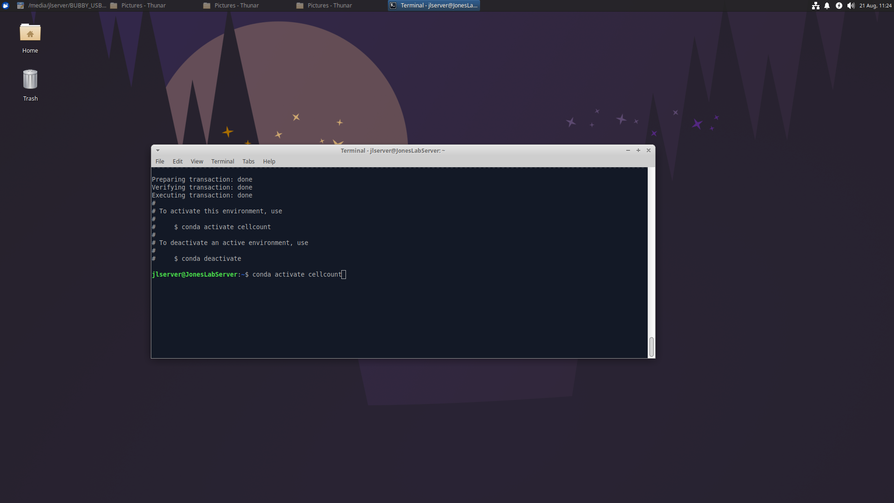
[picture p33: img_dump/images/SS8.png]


Your terminal prompt should now start with `(cellcount)`. 

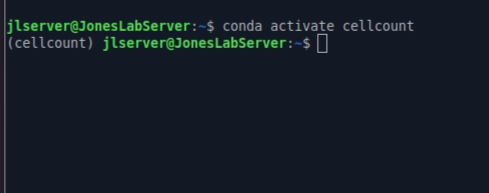
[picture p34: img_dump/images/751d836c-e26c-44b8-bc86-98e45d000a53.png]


**It must stay active for steps 3 and 4**. If you close the terminal for any reason, you will have to restart the environment by running `conda activate cellcount` again.

---

## **3. Install PyTorch**

**This step will decide whether the NVIDIA GPU (If you have one) is used, or whether code should be run on the CPU.** 

Following one of the following steps based on if you have an NVIDIA GPU or not.

### No NVIDIA GPU:

Run this command to install the CPU version of PyTorch.

```python
pip install torch --index-url https://download.pytorch.org/whl/cpu
```

### NVIDIA GPU:

First check what you have by running this command:

```python
nvidia-smi
```

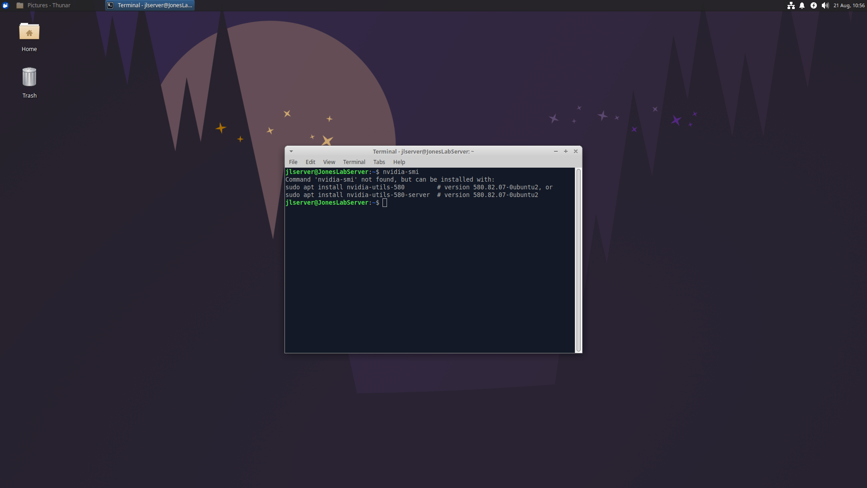
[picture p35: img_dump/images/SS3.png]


Even if you have an NVIDIA GPU, you may have to install nvidia-sma. Install it using one of the commands suggested in the terminal. Then run `nvidia-smi` again.

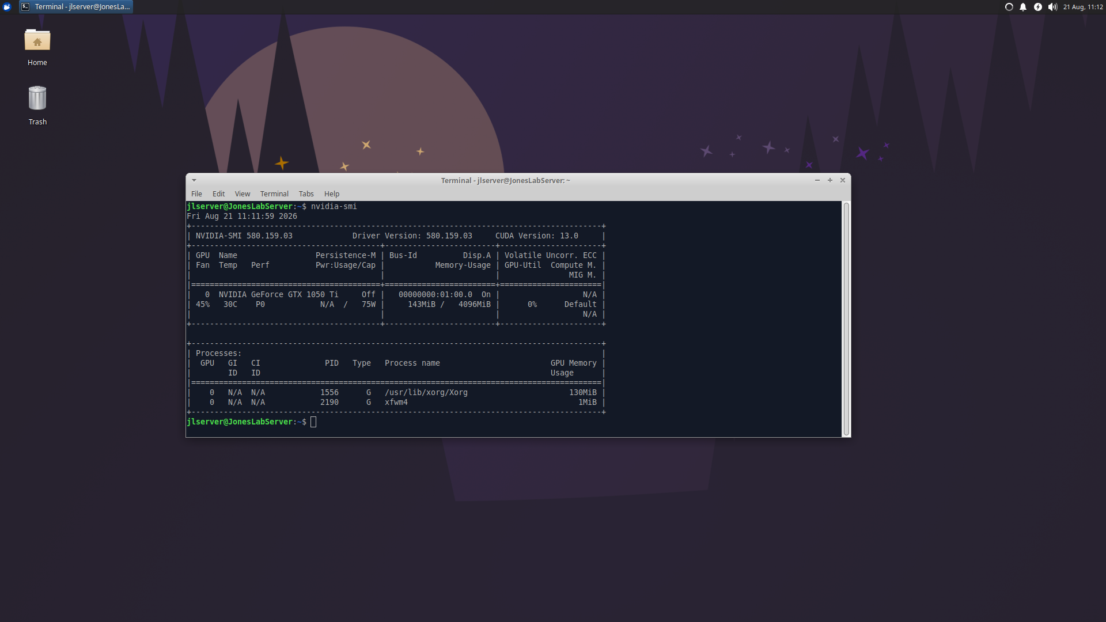
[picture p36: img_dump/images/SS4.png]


Check "CUDA Version" (shown in the screen shot above in the top-right by `nvidia-smi`).

In the commands below, make sure your wheel index no higher than it (`cu126`, `cu128` or `cu130`). I.e. if your CUDA version is 13.0, you should use `cu130` or below. 

Or,  more simply, use the table below to install compatible drivers based the generation of NVIDIA GPU you have. Copy the appropriate command and run it in terminal as before. 

| GPU generation | Install |
| --- | --- |
| Pascal (GTX 10-series)  | `pip install torch==2.6.0 --index-url https://download.pytorch.org/whl/cu126` |
| Turing or newer (RTX 20/30/40/50, GTX 16) | `pip install torch --index-url https://download.pytorch.org/whl/cu128` |

### **BOTH: Install other requirements and verify either path**

After finishing one of the above to setup Pytorch, run the following command in terminal. 

**IMPORTANT**: Make sure you are in the SERVER_FILES directory which contains a lot of the setup files - (enter using `cd ~/cell_counter_repo/SERVER_FILES`). 
If you aren't in the directory, this command and a lot of the ones below will fail. 

```bash
pip install -r requirements.txt
python check_gpu.py
```

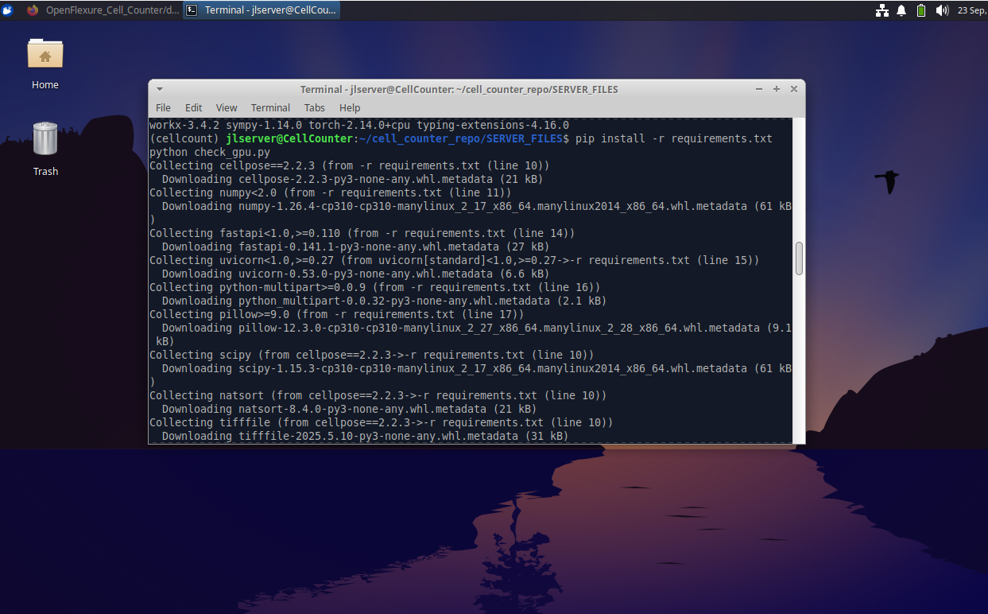
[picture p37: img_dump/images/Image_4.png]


This installs other required python packages, and prints whether the GPU will actually be used, and if not, exactly why.

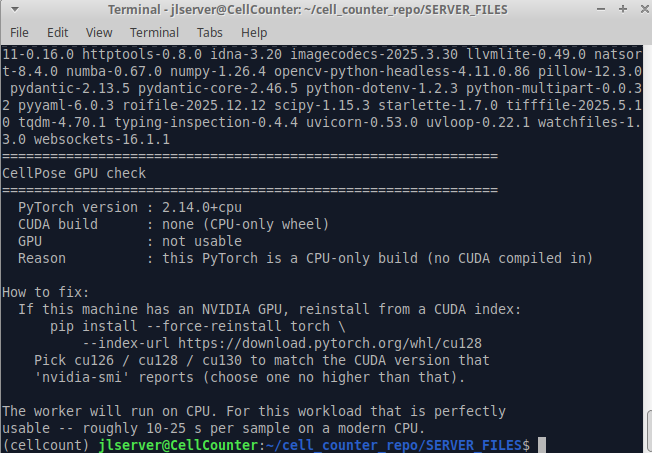
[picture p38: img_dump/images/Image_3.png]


---

## 4. **Download the CellPose model weights**

CellPose fetches its weights on first use. You can skip this step if the server will have internet access at all times. However, this can be required in case your server may lose internet access after moving it closer to the cell counter (my server does not have wifi-capability for example). 

Run the following command in terminal

```python
python fetch_models.py --download
python fetch_models.py --check
```

From now on, you will need your OFM Cell Counter at hand.

---

## **5. Configure the network link**

Connect the server and OFM Cell Counter using an Ethernet cable then run the following command to find the interface name:

```python
ip link
```

(I used ip addr show, but it should look similar)

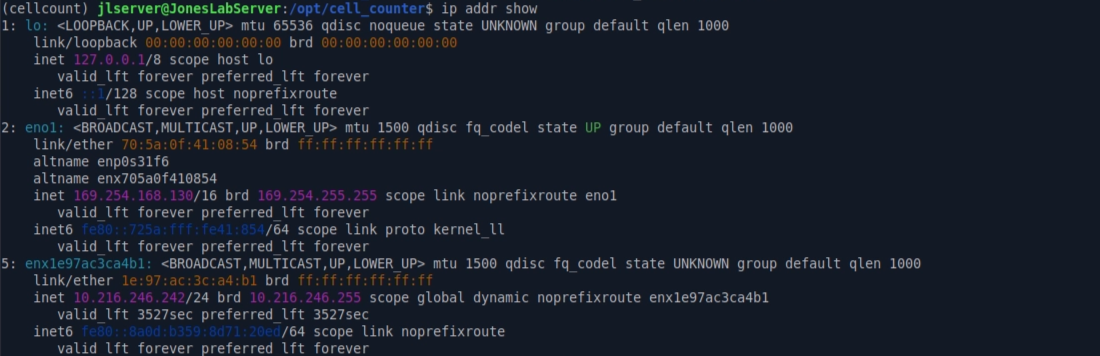
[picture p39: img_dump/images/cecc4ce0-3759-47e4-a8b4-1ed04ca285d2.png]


Look for a wired interface — `enp3s0`, `eno1`, or similar. Not `lo`, and not whichever one carries your normal network. For me, this was eno1. To test this, you can unplug the ethernet, and see which interface dissapears. Keep a note of this name.

I will show two ways of setting up the networking between the server and the OFM Cell Counter. One is using the GUI, and one is by running a code block in command line. 

### **Option A — Graphical**

1. Run `nm-connection-editor` in terminal to open up the networking GUI

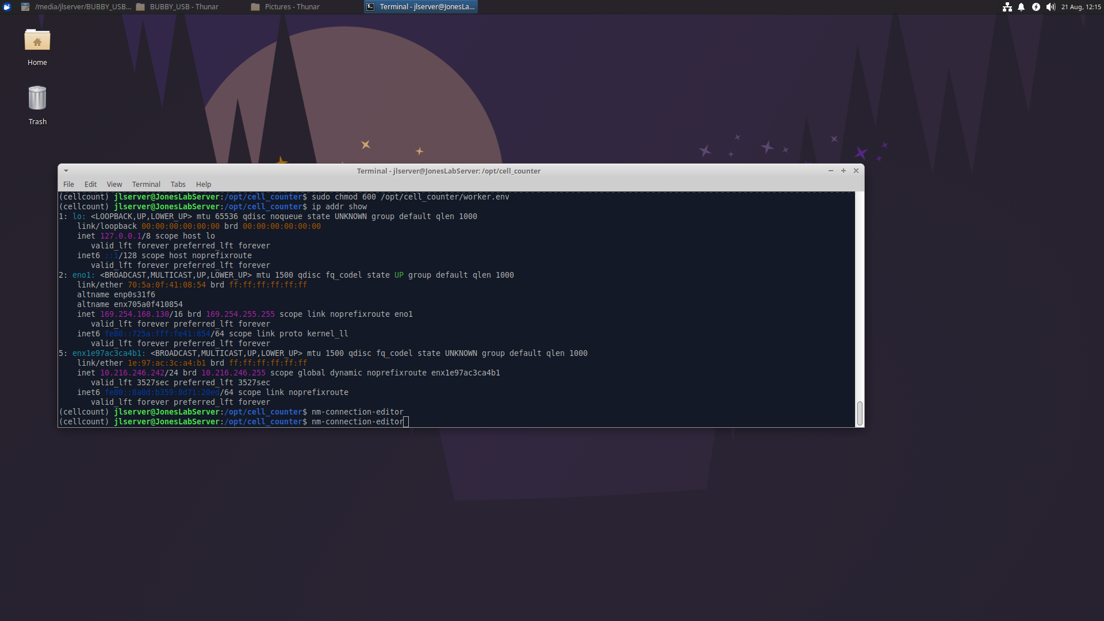
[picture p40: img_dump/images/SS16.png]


2. Select the wired connection for the interface identified above, click the gear icon.

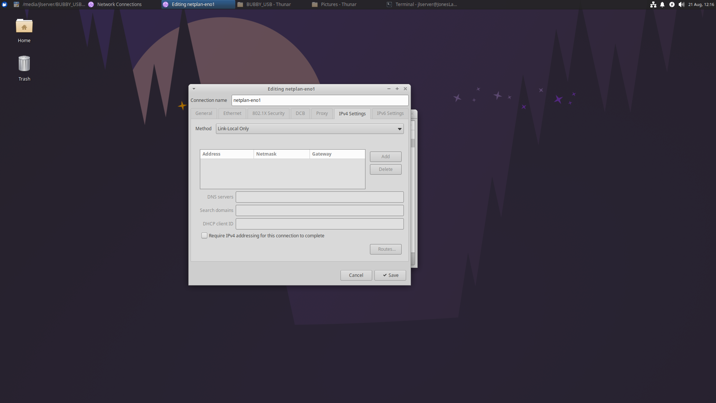
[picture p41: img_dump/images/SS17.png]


3. **IPv4 Settings** → Method: **Manual**.

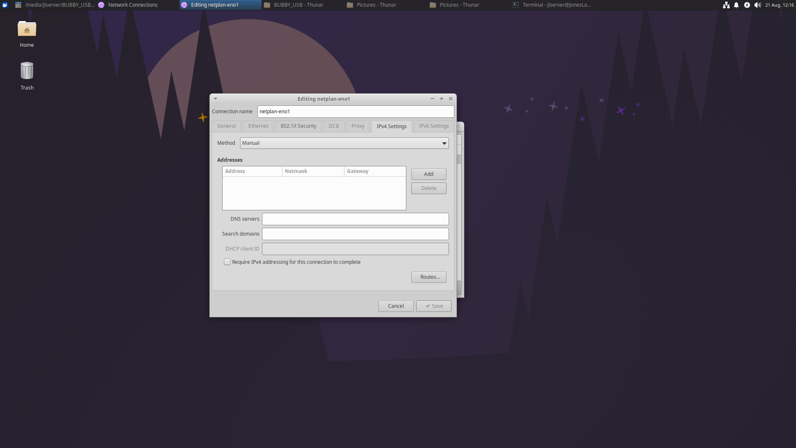
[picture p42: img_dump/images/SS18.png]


4. **Add**: Address `192.168.50.10`, Netmask `255.255.255.0`, Gateway **empty**.

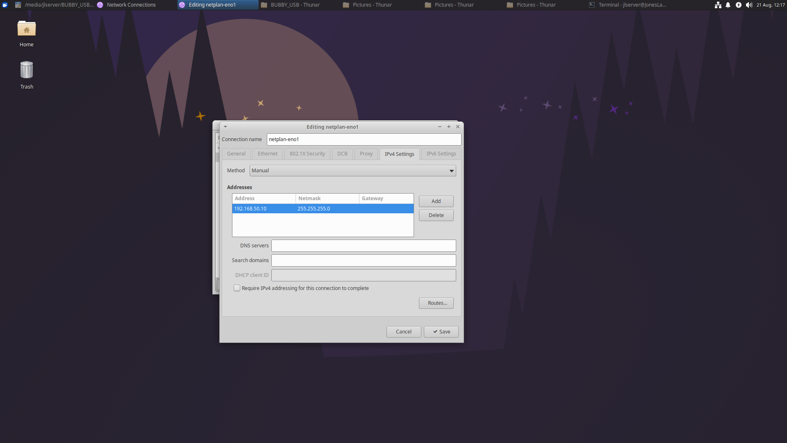
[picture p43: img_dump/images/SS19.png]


5. Click **Routes…** and tick **"Use this connection only for resources on its own network."**

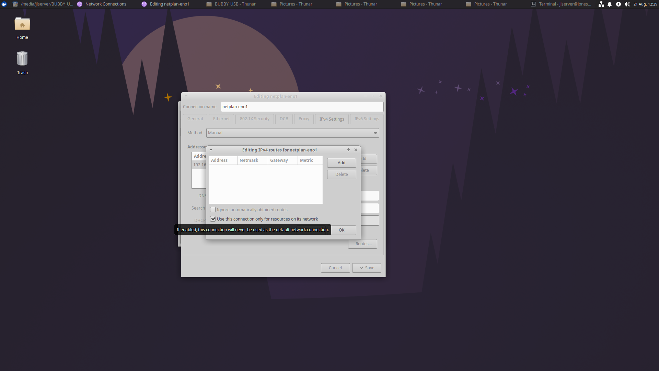
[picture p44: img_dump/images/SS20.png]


6. Save.

### Option B - Command Line

If you’d prefer to avoid using the GUI, run this code block in terminal. 

**IMPORTANT:** Replace `eno1` in the code block below with your interface name! 

```python
sudo nmcli con add type ethernet ifname eno1 con-name direct-link \
  ipv4.method manual \
  ipv4.addresses 192.168.50.10/24 \
  ipv4.never-default yes \
  ipv4.dns-priority 200
sudo nmcli con up direct-link
```

### Verify

Run the following code block to verify the connection is working as expected. Again replace `eno1` in the code block below with your interface name! 

```python
ip addr show eno1      # expect: inet 192.168.50.10/24
ip route | grep default  # expect: ONE default route, NOT via eno1
ping -c 3 192.168.50.1   # the Pi should answer
```

What this should look like:

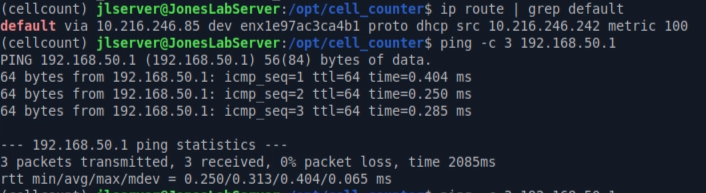
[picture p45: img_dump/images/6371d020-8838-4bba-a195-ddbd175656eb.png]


---

## **7. Install the Worker (Get the server up and running!)**

Now, run the following script, which should for the most part finish the setup for the server.

```python
sudo bash install_service.sh
```

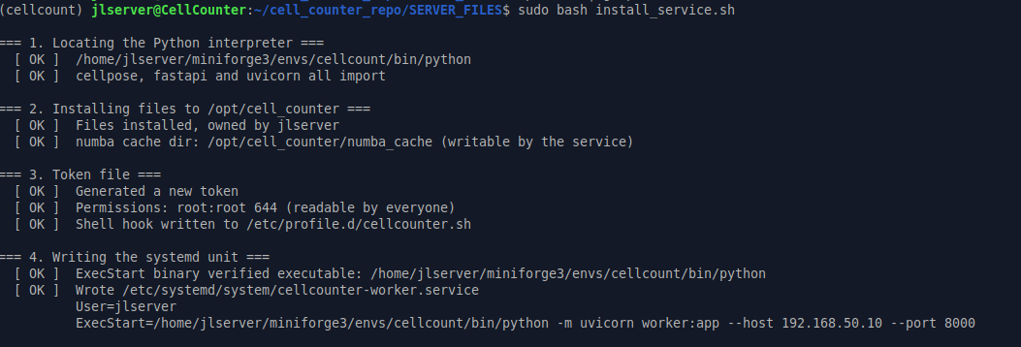
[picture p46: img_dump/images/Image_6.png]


In case you are wondering the script does the following:

- finds your conda Python and checks cellpose, fastapi and uvicorn import
- copies the files to `/opt/cell_counter`
- creates a numba cache directory
- writes the systemd unit with your real username and paths
- enables and starts the service which waits for images from the Pi, runs cellpose models on them to generate masks, and returns them back to the Pi.

The setup should now be complete, however a few verification steps.

---

## **8. Verify the server**

Now run the following commands in the terminal on the server, to make sure everything is working as expected. 

```python
systemctl is-enabled cellcounter-worker   # expect: enabled
systemctl is-active  cellcounter-worker   # expect: active
curl http://192.168.50.10:8000/health
```

The last one should returns something like:

```python
{"status":"ok","model":"cyto2","device":"gpu","loaded":true,"auth_required":true, ...}
```

You may have to wait ~30 s after finishing step 7, for the worker to be up and running. If the curl command does not return the expected result, try again after some time. 

---

## 9. Verify the Cell Counter

**Now on the Cell Counter**: make sure that the cell counter can communicate with the server by running the same command as above in terminal on the cell counter:

```python
curl http://192.168.50.10:8000/health
```

If you see the same response as before: 

```python
{"status":"ok","model":"cyto2","device":"gpu","loaded":true,"auth_required":true, ...}
```

Then the Cell Counter should now be able to use the server for Cellpose segmentation! 

---

## 10. Final Test: Reboot the Server

As a final test, while the server and Cell Counter are still connected, restart the server. 

After about 30s, run the `curl [http://192.168.50.10:8000/health](http://192.168.50.10:8000/health)` command again. If this gets a response, it means the server setup is finished. It can boot up on its own, and can be turned on/off at will. 

---

## Optional: Using custom trained Cellpose Models

---

Getting the server to use custom trained cellpose models is very simple.

**ONLY** If this is your first time adding a custom model to the cell counter, run the following code on the server to make a folder to keep all your custom models in:

```python
sudo mkdir -p /opt/cell_counter/models
sudo chown -R $USER:$USER /opt/cell_counter/models
```

### Changing Models:

Using a USB stick or whichever way you’d like, move the model file for the model you’d like to use into the /opt/cell_counter/models folder. If you would like to use the model I trained on HEK-293 cells, you can find it in the [CELLPOSE_MODELS](/CELLPOSE_MODELS/) directory.

Then, to make the server use this custom model instead of the default cyto2:

First run this:

```python
sudo systemctl edit --full cellcounter-worker
```


In the file that opens up, change the “CELLCOUNT_MODEL” to point to your custom model, e.g. “CP_20260916_120000”. Remember to also change the cellpose diameter "CELLCOUNT_DIAMETER" to whichever diam the model was trained on! 

```python
Environment=CELLCOUNT_MODEL=/opt/cell_counter/models/CP_20260916_120000
```

Then, to restart the server and make sure it is now using your model:

```python
sudo systemctl daemon-reload
sudo systemctl restart cellcounter-worker
journalctl -u cellcounter-worker -n 20 --no-pager
```

The log should confirm `Loading CUSTOM model:` and print the diameter the model was trained at. `/health` will show `"model_is_custom": true`.
